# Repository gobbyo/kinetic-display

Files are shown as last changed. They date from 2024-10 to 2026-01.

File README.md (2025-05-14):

## Introduction

The Kinetic Display is an innovative and engaging way to showcase the current time, date, indoor temperature and humidity, and outdoor temperature and humidity. Watch the feature summary video below to see it in action. This robotic seven-segment clock-like display consists of 4 digits and 2 colons, totaling 30 actuators that extend and retract segments. Each segment lights up when extended and turns off when retracted, creating a satisfying clacking sound with every movement, adding a unique auditory experience.

See the full documentation, assembly instructions, and user guides at [https://gobbyo.github.io/kinetic-display/](https://gobbyo.github.io/kinetic-display/).

**Feature Summary**

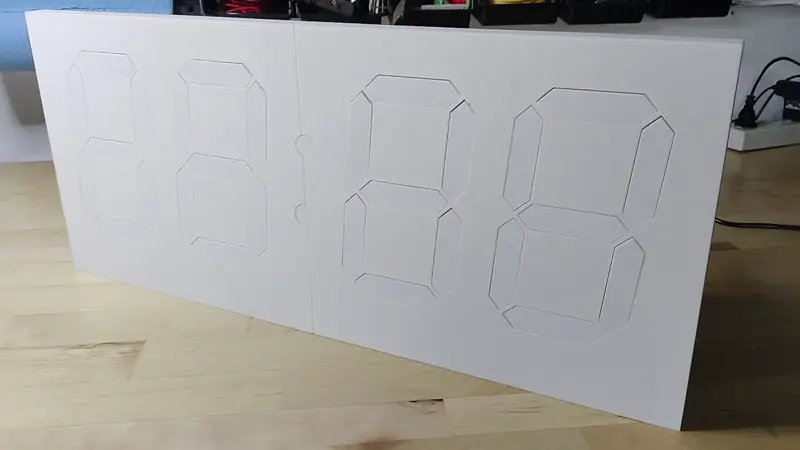
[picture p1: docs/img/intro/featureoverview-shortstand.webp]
summaryfeatures


The display features a built-in web service with adjustable settings that allow you to easily configure and personalize your display using any device with Wi-Fi and a web browser.

display-settings

Having adjustable settings for your kinetic display offers several advantages:

- **Personalization**: Tailor the display's schedule, time format, temperature units, and digit style to match your preferences and environment.
- **Convenience**: Make changes from your phone or computer without needing to reprogram or physically access the device.
- **Adaptability**: Quickly update Wi-Fi credentials, time zones, or schedules if you move the display or your needs change.
- **Reliability**: Built-in test and recovery options help ensure the display operates correctly after power loss or network changes.
- **Energy Efficiency**: Schedule sleep and wake times to save power and extend the life of your display.

Optional startup animation setting whenever the power is turned on or the display wakes up from low power mode.

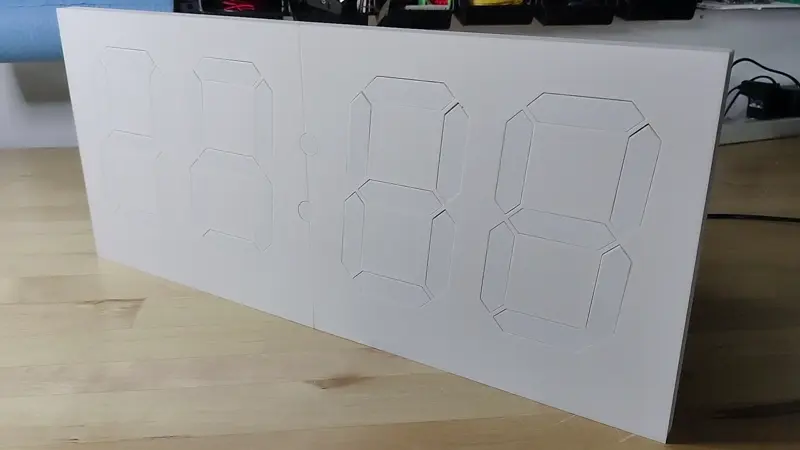
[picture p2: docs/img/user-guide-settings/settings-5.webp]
settings-5


Optional alien digit type setting. See the [table on human and alien digit type](./docs/userguide/digittype.md).

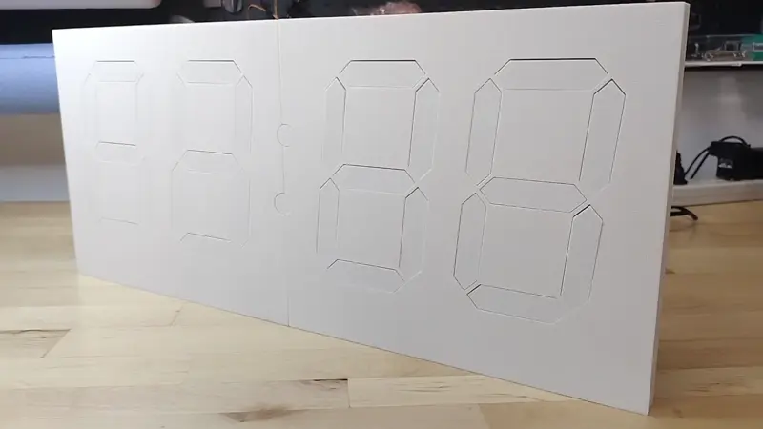
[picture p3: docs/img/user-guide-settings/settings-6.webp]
settings-6


Designed for durability, the display is built to last for years when assembled correctly by following the detailed documentation. Below is an overview of the iterative design process that led to the creation of a robust, reliable, and cost-effective display, fully 3D-printable on a 256mm x 256mm x 256mm build plate.

**Actuator Prototype**

The actuators are the heart of the display, and getting their design right was critical. Early prototypes revealed issues such as gear tooth breakage due to improper sizing, material selection, and abrupt stops during operation. Adjustments to gear dimensions and the use of heavy-duty 103 motors significantly improved performance, enabling smooth operation with lower voltage requirements.
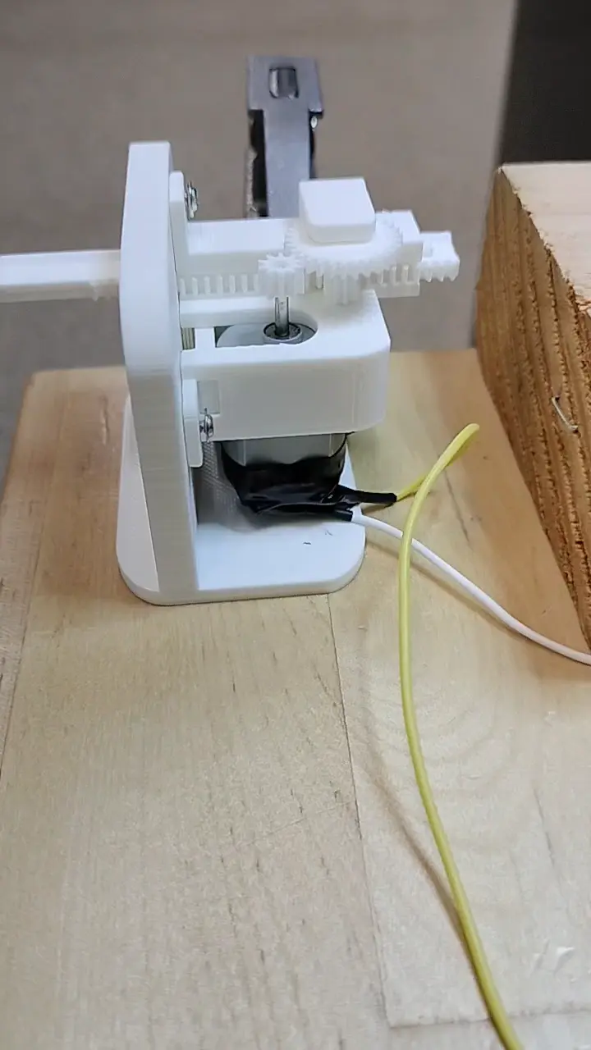
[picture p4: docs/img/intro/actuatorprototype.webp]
actuator


**Segment Prototype**

Multiple iterations of the segment design ensured the robustness of the segment head and its attachment to the rack gear. Experiments also determined the best cushioning material to absorb the impact of constant actuator movement.
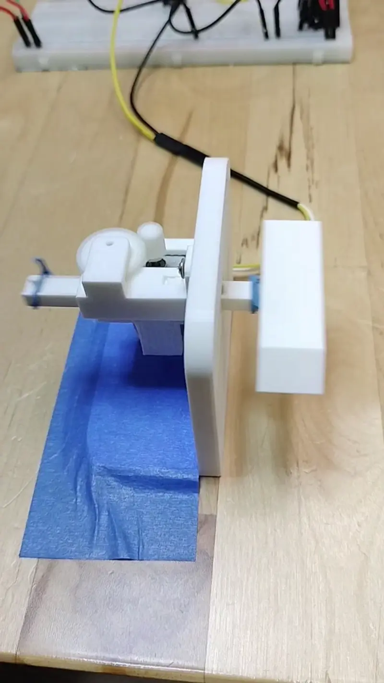
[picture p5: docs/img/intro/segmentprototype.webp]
segment


**Digit Prototype**

The first digit prototype provided valuable insights into PCB design, software requirements, and the optimal dimensions for positioning the seven actuators within a single digit.
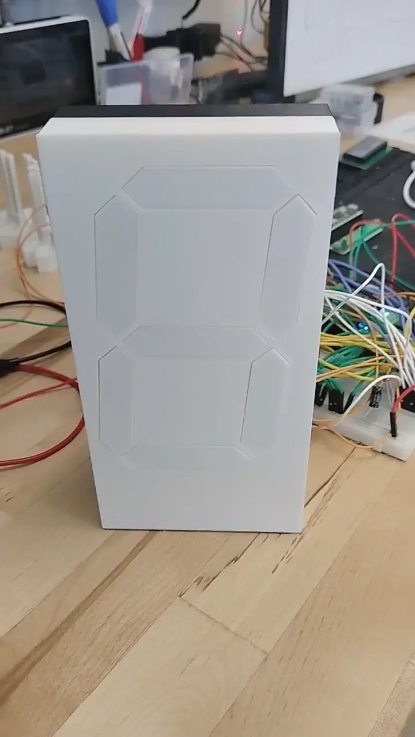
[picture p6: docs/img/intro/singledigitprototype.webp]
digit


**First Prototype**

The prototype below has been running continuously since April 2024, demonstrating the reliability and durability of the design.
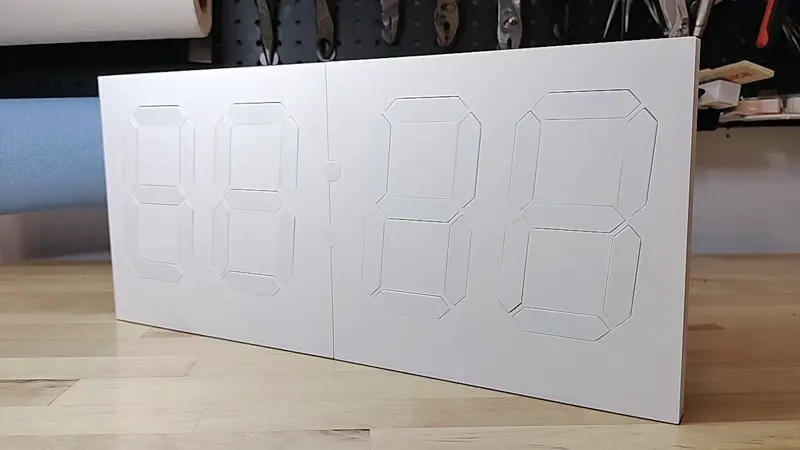
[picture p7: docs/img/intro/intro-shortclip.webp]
display


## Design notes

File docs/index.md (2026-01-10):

# Contents

The links listed below should be followed in the order they appear on the page from top to bottom. Use the `← Previous` and `Next →` buttons on the top menu bar to navigate.

## Start Here

- [Introduction](intro.md)
- [Verify REST API Dependencies](verifyapis.md)
- [Software and Micro Controller Preparation](prerequisitesoftware.md)

## Order Parts

- [Bill of Materials](./createandorder/bom.md)
- [Fabricate the Printed Circuit Boards (PCBs)](./createandorder/pcb.md)
- [Display Parts FDM Fabrication](./createandorder/3dprints.md)

## Assemble and Test Components

- [Actuator Assembly](./assembly/actuatorassembly.md)
- [Digit PCB Assembly](./assembly/digitpcbassembly.md)
- [Deploy Digit Project](./assembly/deploydigitproject.md)
- [Digit PCB Test](./assembly/digitpcbtest.md)
- [Conductor PCB Assembly](./assembly/controllerpcbassembly.md)
- [Deploy Conductor Project](./assembly/deploycontrollerproject.md)
- [Conductor PCB Test](./assembly/controllerpcbtest.md)
- [Power Management PCB Assembly](./assembly/powermanagementpcb.md)
- [Power Management PCB Test](./assembly/powermanagementpcbtest.md)
- [Buck Module Wiring](./assembly/buckmodulesandwiring.md)
- [UART and Relay Wiring](./assembly/uartandrelaywiring.md)
- [Display Face and PCBs Assembly with Integration Testing](./assembly/displayfacepcbs.md)
- [Backplate and Stand Assembly](./assembly/backplateassembly.md)
- [Segment Assembly and Installation](./assembly/segmentassembly.md)
- [Finishing Touch](./assembly/finishingtouch.md)

## User Guide

- [Orientation](./userguide/orientation.md)
- [On/Off Switch](./userguide/spdtswitch.md)
- [Web Service and Settings](./userguide/websettings.md)
- [Schedule Creation and Management](./userguide/schedule.md)
- [Table of Human and Alien Digit Type](./userguide/digittype.md)

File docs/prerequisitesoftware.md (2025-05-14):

# Software and Microcontroller Preparation

If you have any problems with this documentation or the code, please create a [new issue](https://github.com/gobbyo/kinetic-display/issues/new/choose) on the Kinetic-Display GitHub site.

## Prerequisites

Before you begin, please:

- Read and bookmark the [MicroPython installation guide for Raspberry Pi Pico](https://www.raspberrypi.com/documentation/microcontrollers/micropython.html#what-is-micropython).

### 1. Install Required Software

1. [Download and install Visual Studio Code](https://code.visualstudio.com/download).
2. Open VS Code and click the **Extensions** icon on the [Activity Bar](https://code.visualstudio.com/docs/getstarted/userinterface#_basic-layout).
3. Search for and install these extensions from the [Marketplace](https://code.visualstudio.com/docs/editor/extension-marketplace):
    - **Python** by Microsoft
    - **MicroPico** by paulober

### 2. Prepare Your Raspberry Pi Pico

1. Download the [flash_nuke UF2 file](https://github.com/Pwea/Flash-Nuke).
2. Clear your Raspberry Pi Pico before flashing a new build:
    - Unplug your Pico from USB if it is connected.
    - Press and hold the **BOOTSEL** button on your Pico while plugging it into your computer's USB port.
    - Wait for the **RPI-RP2** storage device to appear on your computer.
    - Drag and drop the **flash_nuke.uf2** file onto the RPI-RP2 drive.
3. Download the MicroPython UF2 file for your device:
    - [Raspberry Pi Pico](https://micropython.org/download/RPI_PICO/)
    - [Raspberry Pi Pico W](https://micropython.org/download/RPI_PICO_W/)

---

## Verify MicroPython on Your Raspberry Pi Pico

1. Open Visual Studio Code.
2. On the top menu, select the **ellipsis ...** (if present), then **Terminal → New Terminal**.
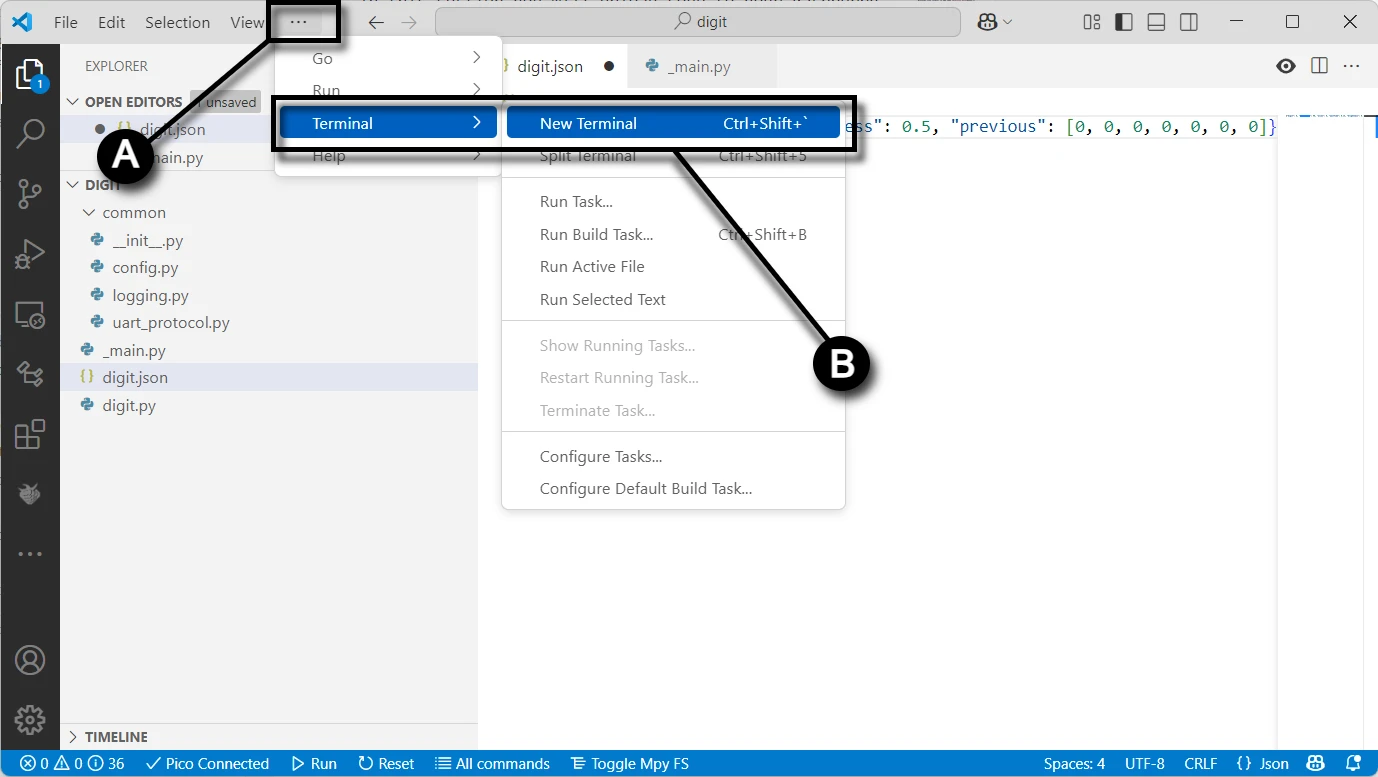
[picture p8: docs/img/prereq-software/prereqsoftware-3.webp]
micropico-0
   
3. In the terminal pane, select the terminal menu, then the MicroPico vREPL sub-menu.
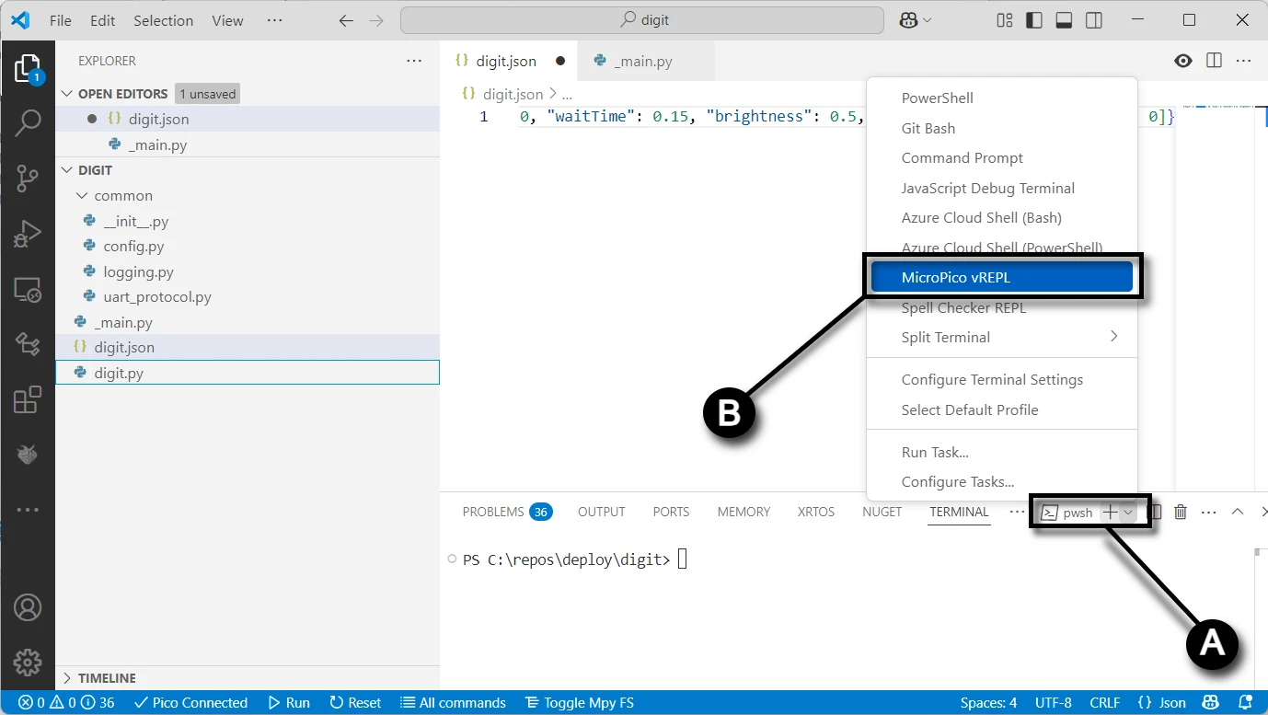
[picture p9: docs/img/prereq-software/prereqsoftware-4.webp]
micropico-1
   
4. Plug your Raspberry Pi Pico into the USB port. The [Status bar](https://learn.microsoft.com/en-us/visualstudio/extensibility/vsix/recipes/notifications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) will show your Pico as connected.
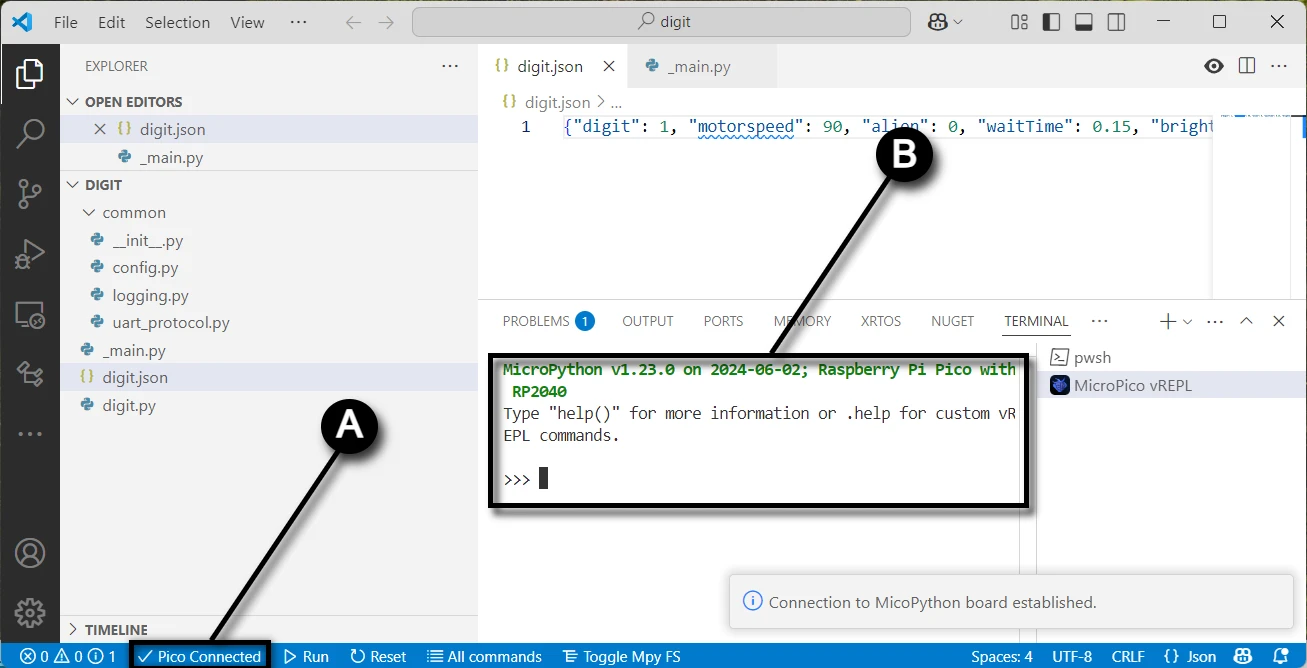
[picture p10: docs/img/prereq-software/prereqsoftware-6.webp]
micropico-3
   
5. Verify your Pico's onboard LED turns on and off by typing the following code in the terminal pane (copy/paste each line separately):

```python
from machine import Pin
p = Pin(25, Pin.OUT)
p.on()
p.off()
```

---

## Fork and Clone the Repository

1. [Install Git](https://git-scm.com/downloads) for Windows.
2. Go to the [Kinetic-Display GitHub repository](https://github.com/gobbyo/kinetic-display).
3. [Create a fork](https://docs.github.com/en/pull-requests/collaborating-with-pull-requests/working-with-forks/fork-a-repo) of the repository.
4. If you have never used PowerShell before:
    - Open a new **PowerShell** terminal as administrator (search for "Windows PowerShell" in the Start menu).
    - Run: `Set-ExecutionPolicy -ExecutionPolicy Unrestricted -Scope CurrentUser`
    - Verify with: `Get-ExecutionPolicy -List` (ensure `CurrentUser` is set to `Unrestricted`).
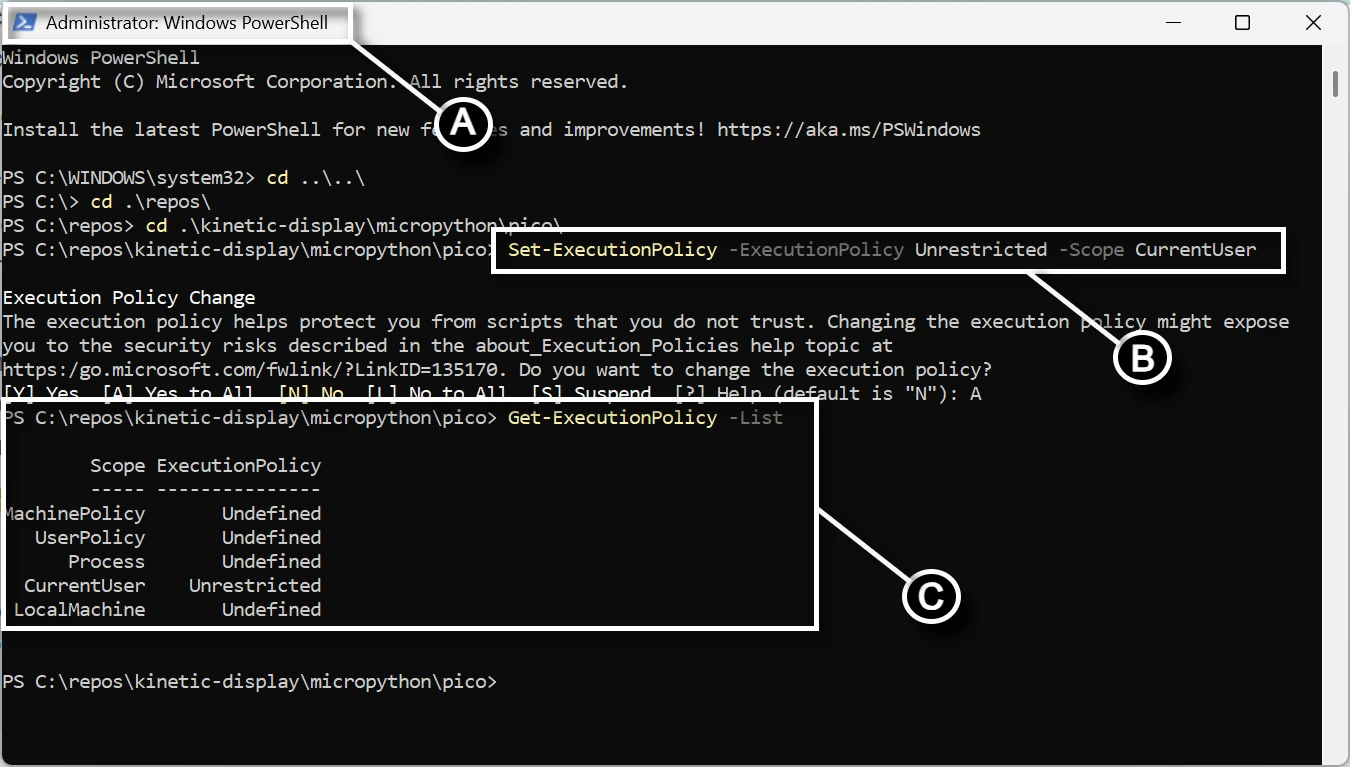
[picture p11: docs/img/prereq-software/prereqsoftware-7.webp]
prereqsoftware-7
    - 
5. Otherwise, open a new **PowerShell** terminal (no admin needed).
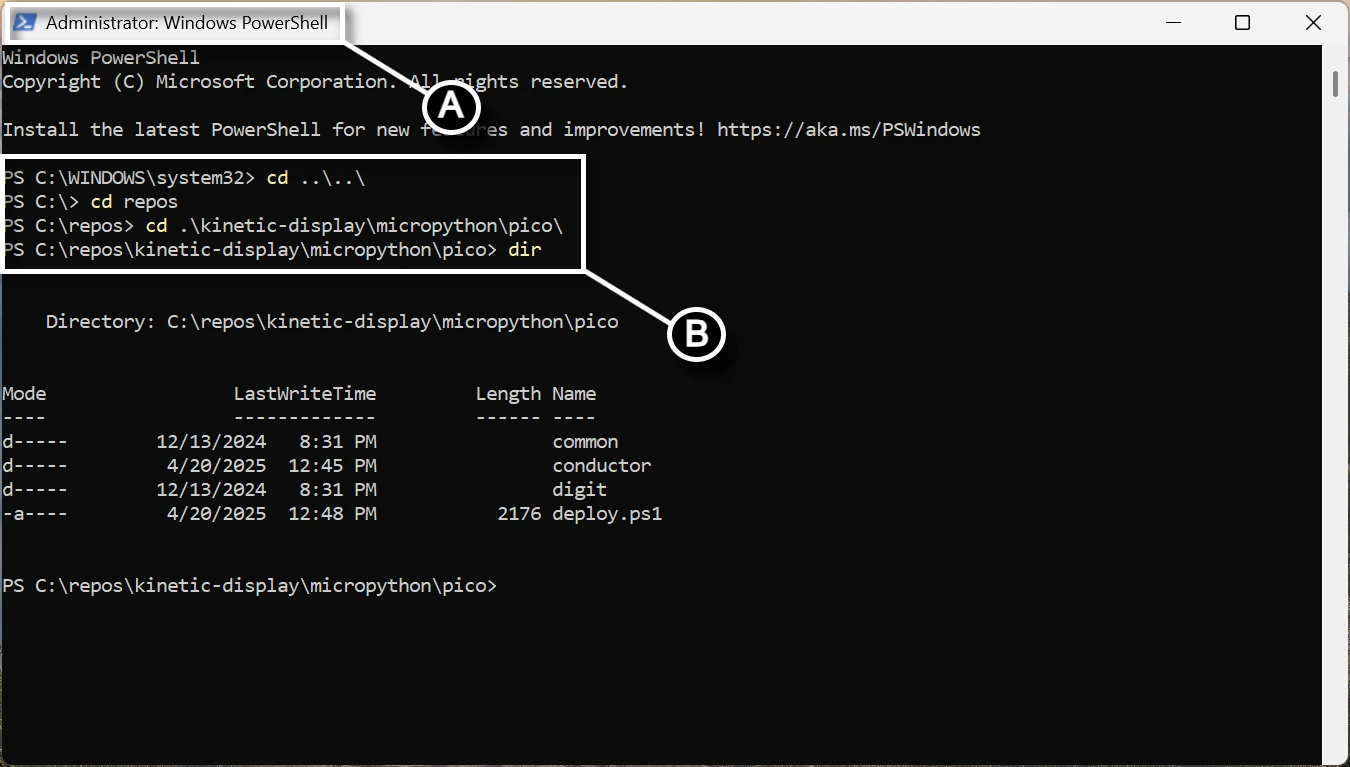
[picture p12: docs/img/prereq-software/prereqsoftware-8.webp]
prereqsoftware-8
   
6. Change directory to your cloned repo's `kinetic-display\micropython\pico` folder.
7. Run the command: `./deploy.ps1 <directorypath>` (replace `<directorypath>` with your desired folder, e.g., `./deploy.ps1 "c:\deploy"`).
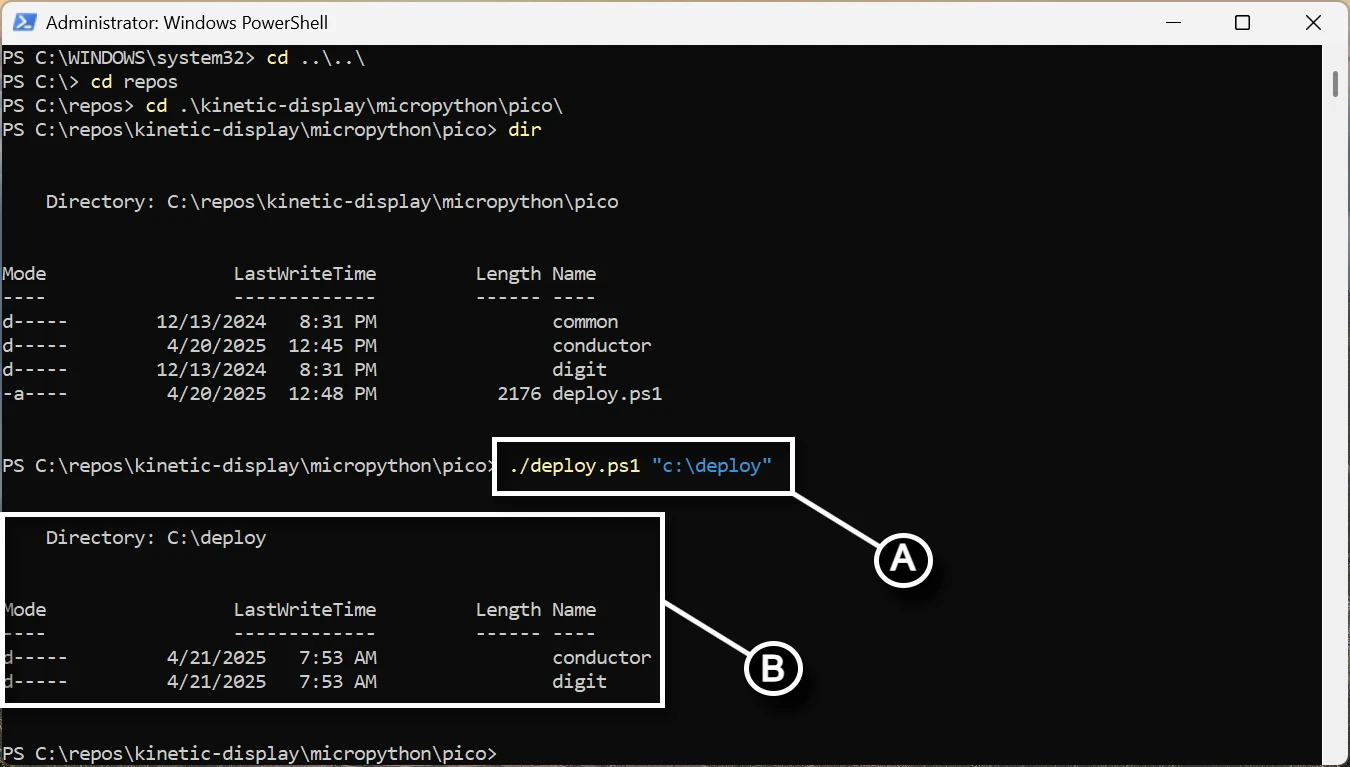
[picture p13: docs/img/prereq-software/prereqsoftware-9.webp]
prereqsoftware-9
   

!!! warning
    The folder you provide for `<directorypath>` will be deleted along with all its contents when you run the `deploy.ps1` script. Be sure to save or rename the folder if you want to preserve any changes you made.

If successful, you should see output like this, and the `conductor` and `digit` folders should exist in your deployment directory:

```dos
Directory: C:\deploy

Mode                 LastWriteTime         Length Name
----                 -------------         ------ ----
d-----         1/31/2025   8:30 PM                conductor
d-----         1/31/2025   8:30 PM                digit
```

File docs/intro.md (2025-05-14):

# Kinetic Display

gobbyo | jbeman@hotmail.com

## Introduction

The Kinetic Display is an innovative and engaging way to showcase the current time, date, indoor temperature and humidity, and outdoor temperature and humidity. Watch the feature summary video below to see it in action. This robotic seven-segment clock-like display consists of 4 digits and 2 colons, totaling 30 actuators that extend and retract segments. Each segment lights up when extended and turns off when retracted, creating a satisfying clacking sound with every movement, adding a unique auditory experience.

**Feature Summary**

summaryfeatures

The display features a built-in web service with adjustable settings that allow you to easily configure and personalize your display using any device with Wi-Fi and a web browser.

display-settings

Having adjustable settings for your kinetic display offers several advantages:

- **Personalization**: Tailor the display's schedule, time format, temperature units, and digit style to match your preferences and environment.
- **Convenience**: Make changes from your phone or computer without needing to reprogram or physically access the device.
- **Adaptability**: Quickly update Wi-Fi credentials, time zones, or schedules if you move the display or your needs change.
- **Reliability**: Built-in test and recovery options help ensure the display operates correctly after power loss or network changes.
- **Energy Efficiency**: Schedule sleep and wake times to save power and extend the life of your display.

Optional startup animation setting whenever the power is turned on or the display wakes up from low power mode.
settings-5

Optional alien digit type setting.
settings-6

Designed for durability, the display is built to last for years when assembled correctly by following the detailed documentation. Below is an overview of the iterative design process that led to the creation of a robust, reliable, and cost-effective display, fully 3D-printable on a 256mm x 256mm x 256mm build plate.

**Actuator Prototype**

The actuators are the heart of the display, and getting their design right was critical. Early prototypes revealed issues such as gear tooth breakage due to improper sizing, material selection, and abrupt stops during operation. Adjustments to gear dimensions and the use of heavy-duty 103 motors significantly improved performance, enabling smooth operation with lower voltage requirements.
actuator

**Segment Prototype**

Multiple iterations of the segment design ensured the robustness of the segment head and its attachment to the rack gear. Experiments also determined the best cushioning material to absorb the impact of constant actuator movement.
segment

**Digit Prototype**

The first digit prototype provided valuable insights into PCB design, software requirements, and the optimal dimensions for positioning the seven actuators within a single digit.
digit

**First Prototype**

The prototype below has been running continuously since April 2024, demonstrating the reliability and durability of the design.
display

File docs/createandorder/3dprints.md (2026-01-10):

# Display Parts FDM Fabrication

## Filament Quantity

Below is a table of quantities of filament by weight. Since a roll of filament is generally 1000g (sometimes a bit less), you'll need two rolls of White Matte PLA.

| Type | Weight (g) |
| :--- | ---: |
| Black Nylon | 77.1g |
| Black Matte PLA| 272.42g |
| White Matte PLA| 1535.44g |
| Black TPU | 115.15g |

</p>

## **1. Black Nylon, Smooth Build Plate**

For Orca and Bambu Studio slicers, see `fdm\3mf\nylon-smooth-black.3mf`.

| File | Description | Density | Quantity | Per Unit (g) | Total (g) |
| :--- | :--- | ---: | ---: | ---: | ---: |
| `digit-gear30.stl` | Pinion gear for digits and colons | 100% | 30 | 1.1  | 33.0 |
| `rack-gear.stl` | The arm of the actuator that extends and retracts the segment | 25% | 30 | 1.47 | 44.1 |

</p>

## **2. Black Matte PLA, Smooth Build Plate**

For Orca and Bambu Studio slicers, see `fdm\3mf\pla-smooth-black.3mf`.

| File | Description | Density | Quantity | Per Unit (g) | Total (g) |
| :--- | :--- | ---: | ---: | ---: | ---: |
| `digit-back-plate.stl`| Back plates for digits 0 and 3 for mounting the actuators | 50% | 2 | 47.43 | 142.29 |
| `digit-gear10.stl` | Motor shaft gear mounted onto the heavy-duty 103 motors | 100% | 30 | 0.5 | 15 |
| `digit1-back-plate.stl`| Conductor and digit 1 back plate for mounting the actuators | 50% | 1 | 67.7 | 67.7 |
| `digit2-back-plate.stl`| Back plate for digit 2 for mounting the actuators and powerbank/display stand | 50% | 1 | 47.43 | 47.43 |

</p>

## **3. White Matte PLA, Smooth Build Plate**

You have two options: `powerbank.stl` or `powerbank-small.stl`. Print the `powerbank.stl` and `powerbank-cover.stl` if you have household animals that might have access to the back of the display. Print `powerbank-small.stl` to keep a lower profile of the back of the display. Mounting `powerbank.stl` and `powerbank-small.stl` is the same for both sizes.

For Orca and Bambu Studio slicers, see `fdm\3mf\pla-smooth-white.3mf`.

| File | Description | Density | Quantity | Per Unit (g) | Total (g) |
| :--- | :--- | ---: | ---: | ---: | ---: |
| `digit-motor-mount.stl`| Motor mount for digits and colons | 100% | 30 | 12.77 | 383.1 |
| `powerbank-cover.stl` | Cover for large stand (optional) | 100% | 1 | 65.53 | 65.53 |
| `powerbank.stl` | Large stand (optional), buck converter mounts, and powerbank PCB mount | 100% | 1 | 146.75 | 146.75 |
| `powerbank-small.stl` | Small stand (preferred), buck converter mounts, and powerbank PCB mount | 100% | 1 | 116 | 116 |
| `rackgear-bumper.stl` | Stops the segment or colon at the precise distance when extended | 100% | 30 | 0.61 | 18.3 |
| `seg-pin.stl` | Pin to hold the rack gear onto the segment and colons | 100% | 30 | 0.4 | 12 |

## **4. White Matte PLA, Textured Build Plate**

For Orca and Bambu Studio slicers, see `fdm\3mf\pla-textured-white.3mf`.

| File | Description | Density | Quantity | Per Unit (g) | Total (g) |
| :--- | :--- | ---: | ---: | ---: | ---: |
| `colon-seg.stl` | Colon, upper and lower | 100% | 2 | 1.88 | 3.76 |
| `digit0-1-face.stl` | Kinetic display face, right side (when facing the front, textured surface side) | 70% | 1 | 395 | 395 |
| `digit2-3-face.stl` | Kinetic display face, left side (when facing the front, textured surface side) | 70% | 1 | 399 | 399 |
| `seg-a.stl` | Digit 7-segment A | 100% | 4 | 4 | 16 |
| `seg-b.stl` | Digit 7-segment B | 100% | 4 | 4 | 16 |
| `seg-c.stl` | Digit 7-segment C | 100% | 4 | 4 | 16 |
| `seg-d.stl` | Digit 7-segment D | 100% | 4 | 4 | 16 |
| `seg-e.stl` | Digit 7-segment E | 100% | 4 | 4 | 16 |
| `seg-f.stl` | Digit 7-segment F | 100% | 4 | 4 | 16 |
| `seg-g.stl` | Digit 7-segment G | 100% | 4 | 4 | 16 |

## **5. Black TPU, Smooth Build Plate**

For Orca and Bambu Studio slicers, see `fdm\3mf\tpu-smooth-black.3mf`.

| File | Description | Density | Quantity | Per Unit (g) | Total (g) |
| :--- | :--- | ---: | ---: | ---: | ---: |
| `digit-gasket.stl` | Gaskets for digits 0 and 3 to cushion the PCB during segment retractions | 15% | 2 | 17.86 | 53.58 |
| `digit1-gasket.stl` | Gasket for the conductor and digit 1 to cushion the PCB during segment retractions | 15% | 1 | 31.71 | 31.71 |
| `digit2-gasket.stl` | Gasket for digit 2 to cushion the PCB during segment retractions | 15% | 1 | 17.86 | 17.86 |
| `rackgear-bumper-gasket.stl` | Provides some cushion for the rack gear when extended | 100% | 30 | 0.4 | 12 |

## Guidelines

Below are a few guidelines to keep in mind when printing and assembling the display:

- **Read the assembly guides**: Read all the assembly guides in this documentation before printing to ensure you have a clear understanding of the fabrication type, quality, positioning, and assembly.
- **Use the provided 3MF and STL files**: The 3MF project files are included under the `./fdm/3mf` directory for Bambu Studio or Orca Slicer users. All necessary settings are included at an object level, not on a global level. STL files are included under the `./fdm/stl` directory.
- **Consistent filament usage**: The display face uses over 2/3rds of a 1 KG roll of filament. Use the same roll of filament when printing both halves of the display face, segments, and colons. Ensure you have two 1 KG rolls of white filament from the same batch to avoid inconsistencies in print color.
- **Dry your filament**: Thoroughly dry your filament before use, especially nylon and flexible filament types. Wet filament can cause stringy prints and result in inexact gear teeth or hole sizes.
- **Adhesion to the print bed**: Apply an adhesive to the printer plate bed to prevent warping of edges and corners. For example, all-weather Aqua Net super hold hairspray provides an even coating of adhesive across the bed plate and results in clean corners and edges.
- **Organize printed parts**: Use painter's tape to keep the pieces organized. See the picture below for an example. Note that segments A-G (left to right) are preserved the moment the bed plate is removed from the 3D printer.  
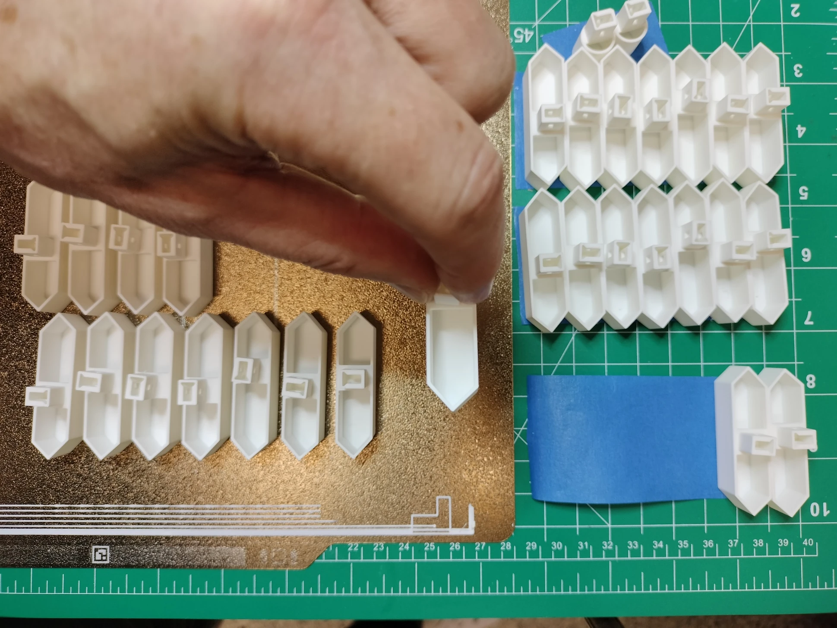
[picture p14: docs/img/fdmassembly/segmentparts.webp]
fdmassembly
  
- **Ironing is optional**: Do not worry if your 3D printer and slicer cannot iron the top surfaces. Ironing is for fit and finish and will not affect the functionality of the display.

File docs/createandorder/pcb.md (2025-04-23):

# Fabricate the Printed Circuit Boards (PCBs)

This guide will help you order the fabrication of your PCBs. The PCB files are located in your fork at `kinetic-display\pcb`. Follow the instructions below to place a separate order for each of the three Gerber files:

- `Gerber_KineticDisplay-Controller`
- `Gerber_KineticDisplay-PowerSystem`
- `Gerber_KineticDisplay-SingleDigit`

You will need to order more PCBs than required for this project because most PCB fabrication facilities have a minimum order quantity of five. Be sure to also order the remaining components and materials from the [Bill of Materials (BOM)](bom.md).

## Steps to Order PCBs

1. Open your browser and navigate to [https://jlcpcb.com/](https://jlcpcb.com/). Create an account if you do not already have one, then click the **Order now** button.  
   Click the 'order now' button
2. Upload the Gerber file by clicking the **Add Gerber file** button. Repeat this step through step 4 for each of the three Gerber files found under the `kinetic-display\pcb` directory.  
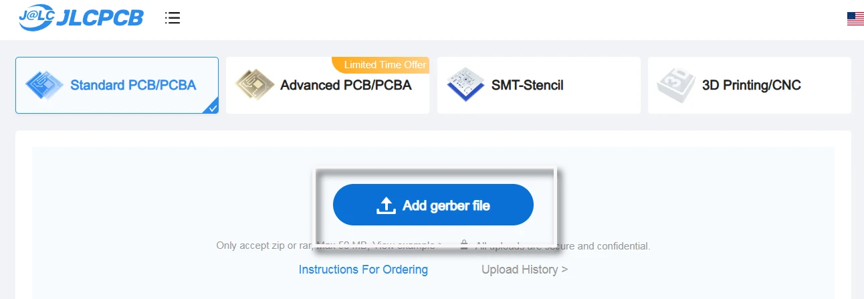
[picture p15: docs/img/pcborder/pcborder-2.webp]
Click the 'Add Gerber file' button
   
3. Use all the default settings except change the PCB color to **white** to enhance the luminosity of the LEDs.  
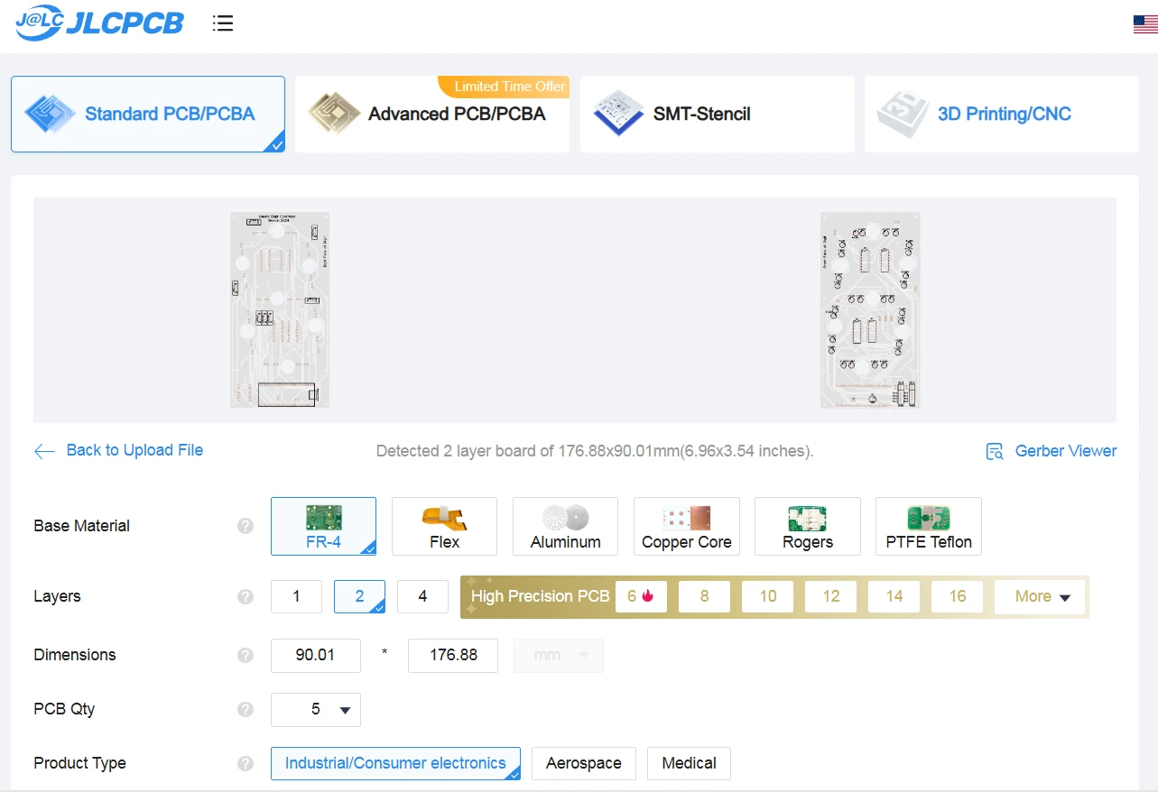
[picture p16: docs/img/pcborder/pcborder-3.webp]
   
4. Click the **SAVE TO CART** button and complete the order by following the shipping and payment steps in the wizard.  
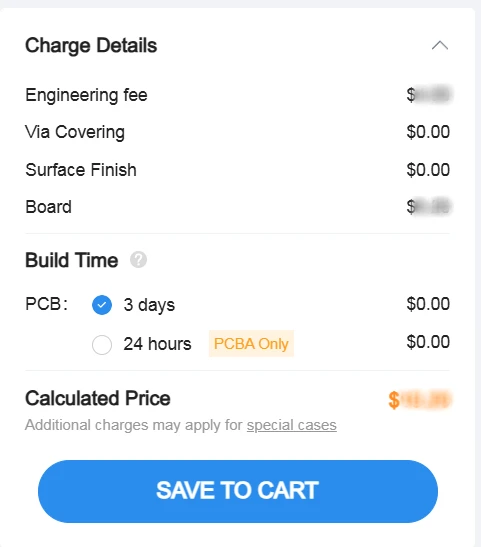
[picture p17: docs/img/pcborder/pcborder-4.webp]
   

## Notes

- **PCB Color**: White PCBs are recommended to maximize LED brightness and improve the overall aesthetic of the display.
- **Minimum Order Quantity**: Most PCB manufacturers require a minimum order of five PCBs per design. This means you will receive extra PCBs, which can be used as spares or for future projects.
- **Shipping and Lead Time**: Be sure to check the estimated shipping time and lead time for fabrication when placing your order.

Congratulations on ordering your PCBs!

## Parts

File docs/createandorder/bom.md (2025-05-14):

# Bill of Materials

| Item | Quantity |
|---|---|
| Single digit PCB for digits 0, 2, & 3 | 3 |
| Conductor PCB for digit 1 and the colons | 1 |
| Powerbank PCB | 1 |
| 2 Inch Jumbo Paper Clips (Smooth Big Paperclips) | 20 |
| M1.7 x 6mm Stainless Steel Phillips Round Head Self Tapping Screws | 200 |
| M1.7 x 8mm Stainless Steel Phillips Round Head Self Tapping Screws | 200 |
| M2 X 15mm Stainless Steel Phillips Round Head Self Tapping Screws | 50 |
| Micro 130 DC Motor Strong Magnetic Brushed Electric DC 3V -12V 25000 RPM Cars Toys Electric Motor, High Speed Torque | 30 |
| Black 28 AWG Gauge Flexible Silicone Rubber Electric Wire | 10M |
| White 28 AWG Gauge Flexible Silicone Rubber Electric Wire | 10M |
| Male Breakout Pin Connector 2.54mm | 100 |
| 2.54mm 0.1" Pitch PCB Mount Screw Terminal Block Connector, 2P 3P 4P Terminals for 26-18AWG Cable | 50 |
| Dupont Jumper Wire Cable Female Pin Connector 2.54mm | 100 |
| 2.54mm 1x2p Dupont Connector Housing Female for Dupont Cable and Jumper Wire | 100 |
| Digital Temperature and Humidity Sensor DHT22 Module, 3 pin | 1 |
| 5mm 0.5 Ω ohm Photoresistor Resistor 5516 GL5516 | 1 |
| 5mm Flat Top LED Diode Lights[^1] (Clear Transparent Lens) Bright Lighting Bulb Lamps Electronics Components Indicator Light Emitting Diodes | 112 |
| 3mm Flat Top LED Diode Lights[^1] (Clear Transparent Lens) Bright Lighting Bulb Lamps Electronics Components Indicator Light Emitting Diodes | 2 |
| Vertical Slide Switches Micro High Knob 3 Pin 2 Position 1P2T SPDT Panel Mount AC 125V 2A | 1 |
| LM2596 DC-DC Step Down Variable Volt Regulator Input 3.2V-40V Output 1.25V-35V Adjustable Buck Converter Electronic Voltage Stabilizer Power Supply Module | 5 |
| 2.1mm Barrel Jack 5.5x2.1mm Female DC Power Jack 2.1 X 5.5mm DC Jack Connector 6V 9V 12V DC Jack Panel Mount | 1 |
| 12V 5A Power Supply, AC DC Converter 100-220V to 12 Volt 5 Amp Transformer 5.5x2.1mm Plug | 1 |
| S8050D S8050 NPN Transistor TO-92 20V 700MA 1W | 1 |
| 1N4001 Diode, standard, 1A, 50V, DO-41 | 1 |
| (optional) 20pin x 10pcs Female Headers Pins Straight Single Row Gold Plated Pitch 2.54mm 0.1 inch for PCB Connector Machine Breadboard Electronic Circuit Board | 10 |
| SONGLE SRS-05VDC-SL 05VDC-SL 4100 Blue 5V 6PIN Power Relay | 1 |
| L293D 16-pin IC Stepper Motor Drivers Controller | 17 |
| 0.1uF Ceramic Disc Capacitor - 50 Volts | 5 |
| 1uF Electrolytic Capacitor 1UF-50V-5X11 | 5 |
| S8550 TO-92 PNP Transistor | 1 |
| 2N2222 TO-92 NPN Transistor | 1 |
| 10K ohm 0805 Resistor 1/4w Metal Film Fixed Resistor | 2 |
| 1K ohm 0805 Resistor 1/4w Metal Film Fixed Resistor | 1 |
| Raspberry pi 2040 Pico | 4 |
| Raspberry pi 2040 Pico-W | 1 |
| Superglue (small tube) | 1 |
| White Matte PLA Filament, 1 KG | 2 |
| Black Matte PLA Filament, 1 KG | 1 |
| Black Nylon Filament, 1 KG | 1 |
| Black TPU Filament, 1 KG | 1 |

## Tools

- 3D printer
- Wire Stripper for 28 AWG stranded wire
- Small Philips head screwdriver
- Dupont connector tool
- Soldering station with solder/flux
- Needle nose pliers
- Tweezers
- Clamping tweezers
- Zinc strip or thin metal strip (for melting PLA)
- Wire snipper
- Multimeter
- Breadboard and jumpers for testing electronics
- Label maker (optional)
- Computer with USB connector

[^1]: You can choose any color of LED that you would like for your display. White LEDs are the easiest to work with as they may have minor color variation within the same batch. Colored LEDs like blue or warm white may greatly vary in color within the same batch. Therefore, you may need to order more than the quantity listed in the BOM to get enough LEDs of the same color. Be sure to test your LEDs by using your phone's digital camera to see if there are any variations in color when the LEDs are lit. Below is a photo showing the color variation of blue 5mm LEDs within the same batch using a breadboard's power rail with 2.63v. In this case, I used the purple-hued LEDs because there were 112 of the same color.  
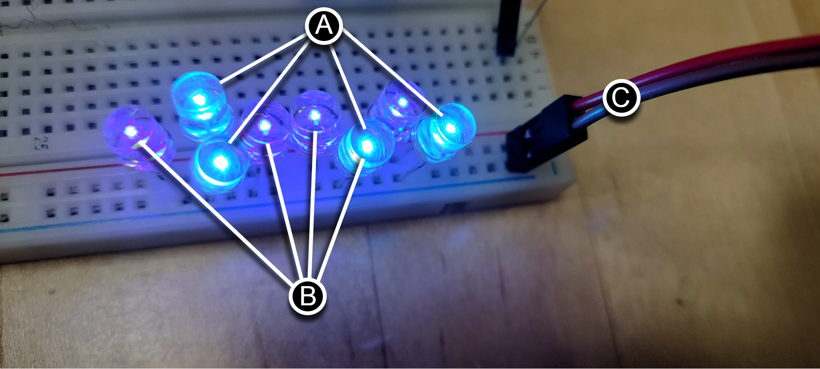
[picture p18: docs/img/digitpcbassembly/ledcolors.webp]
blueLEDs


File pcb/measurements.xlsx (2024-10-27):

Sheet: bom
Quantity | Item | Items Per Package | Quantity per Package | Unit cost | Sub Total | % of overall cost | Cost DIY
4 | RP2040-Pico Microcontroller | 1 | 2 | $7.00 | $14.00 | 9.1% | $14.00
1 | ESP32 S2 Mini WIFI Microcontroller | 1 | 1 | $5.00 | $5.00 | 3.3% | $5.00
18 | L293D Stepper Push-Pull Motor Driver Controllers IC 16-Pin DIP-16 4.5V-36V | 10 | 1.8 | $8.99 | $16.18 | 10.5% | $17.98
30 | Micro 130 DC Motor Strong Magnetic Brushed Electric DC 3V -12V, 17g weight | 10 | 3 | $11.99 | $35.97 | 23.4% | $35.97
120 | 5mm Flat Top LED Diode Lights (Clear Transparent Lens) | 100 | 1.2 | $6.99 | $8.39 | 5.5% | $13.98
2 | Self Adhesive Felt Sheet, Peel and Stick, 2mm thick, A4 Size (8.3" x 11.8") | 4 | 0.5 | $4.99 | $2.50 | 1.6% | $4.99
2 | Self Adhesive Felt Sheet, Peel and Stick Felt Liner, A4 Size (8.3" x 11.8") | 10 | 0.2 | $7.99 | $1.60 | 1.0% | $7.99
60 | Dupont Jumper Wire Cable Female Pin Connector 2.54mm | 200 | 0.3 | $6.99 | $2.10 | 1.4% | $6.99
30 | Dupont 2 Plug Connector Housing | 200 | 0.15 | $11.99 | $1.80 | 1.2% | $11.99
32 | M2x15mm Thread Nickel Plated Round Head Self Tapping Screws | 50 | 0.64 | $7.49 | $4.79 | 3.1% | $7.49
32 | M1.7x8mm Thread Nickel Plated Round Head Self Tapping Screws | 100 | 0.32 | $10.39 | $3.32 | 2.2% | $10.39
90 | M1.7x6mm Thread Nickel Plated Round Head Self Tapping Screws | 100 | 0.9 | $9.99 | $8.99 | 5.9% | $9.99
5 | 1u capacitor | 80 | 0.0625 | $6.99 | $0.44 | 0.3% | $6.99
5 | 0.1u capacitor | 25 | 0.2 | $5.50 | $1.10 | 0.7% | $5.50
1 | 5mm 5 ohm photoresistor GL5539 | 20 | 0.05 | $5.49 | $0.27 | 0.2% | $5.49
1 | DHT11 (3 pin) temperature and humidity sensor | 10 | 0.1 | $12.99 | $1.30 | 0.8% | $12.99
2 | 5V 0.3A Mini Size Black SPDT Slide Switch | 20 | 0.1 | $6.89 | $0.69 | 0.4% | $6.89
1 | USB 3.1 Type C Connector Board, Serial Basic Breakout Female Connector | 10 | 0.1 | $8.59 | $0.86 | 0.6% | $8.59
10 | Large Paper Clips, Jumbo 2 inch smooth | 300 | 0.03333333333 | $8.99 | $0.30 | 0.2% | $8.99
1 | DC 5.1v 5A Power Supply | 1 | 1 | $12.99 | $12.99 | 8.5% | $12.99
4 | PCB Digit | 5 | 0.8 | $30.89 | $24.71 | 16.1% | $30.89
1 | PCB Controller | 5 | 0.2 | $30.89 | $6.18 | 4.0% | $30.89
 | Total |  |  |  | $153.48
 | Tax |  |  | 8.80% | $166.98
 | DIY Total |  |  |  | $276.97
 | DIY w Tax |  |  |  | $301.34

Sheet: pcb holes
 | X (mm) | Y (mm)
dimensions | 94 | 154
midpoint | -47 | 77
hole-seg-a | -2.4 | 60.5
hole-seg-b | -33.9 | 31.6
hole-seg-c | -28.96 | -29.92
hole-seg-d | 7.3 | -61.92
hole-seg-e | 31.74 | -24.52
hole-seg-f | 27 | 29.4
hole-seg-g | -2.4 | 0.1
hole-seg-a-tab-a | -14.4 | 61
hole-seg-a-tab-b | 18.34 | 63
hole-seg-a-tab-c | 10.59 | 39.21
hole-seg-b-tab-a | -34.65 | 19.62
hole-seg-b-tab-b | -36.69 | 52.36
hole-seg-b-tab-c | -12.83 | 44.62
hole-seg-c-tab-a | -40.95 | -29.19
hole-seg-c-tab-b | -8.2 | -27.15
hole-seg-c-tab-c | -15.95 | -51.02
hole-seg-d-tab-a | 6.57 | -73.92
hole-seg-d-tab-b | 4.53 | -41.17
hole-seg-d-tab-c | 28.39 | -48.92
hole-seg-e-tab-a | 43.73 | -25.37
hole-seg-e-tab-b | 10.99 | -27.4
hole-seg-e-tab-c | 18.74 | -3.54
hole-seg-f-tab-a | 27.8 | 41.38
hole-seg-f-tab-b | 29.84 | 8.63
hole-seg-f-tab-c | 5.98 | 16.38
hole-seg-g-tab-a | 9.62 | -0.95
hole-seg-g-tab-b | -23.12 | -2.99
hole-seg-g-tab-c | -15.37 | 20.87
hole-mount-a | -41.5 | 74
hole-mount-b | 41.5 | 74
hole-mount-c | -41.5 | 0
hole-mount-d | 41.5 | 0
hole-mount-e | -41.5 | -65
hole-mount-f | 41.5 | -65
hole-mount-g | -41.5 | -95.5
hole-mount-h | 41.5 | -95.5
hole-upper-inside-a | -25 | 50
hole-upper-inside-b | 15 | 50
hole-upper-inside-c | -21 | 10
hole-upper-inside-d | 19 | 10
hole-lower-inside-a | 19 | -10
hole-lower-inside-b | -21 | -10
hole-lower-inside-c | 15 | -50
hole-lower-inside-d | -25 | -50

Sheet: pcb sizes
 | mm | pixel
width | 90 | 340
height | 176 | 666
ppi

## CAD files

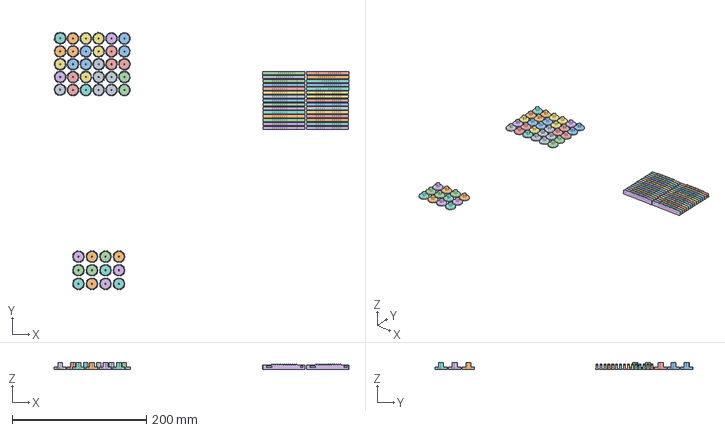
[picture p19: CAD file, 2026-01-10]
fdm/3mf/nylon-smooth-black.3mf
439.9 x 384.4 x 9.70 mm
digit-gear30.stl x 42
rack-gear.stl x 30

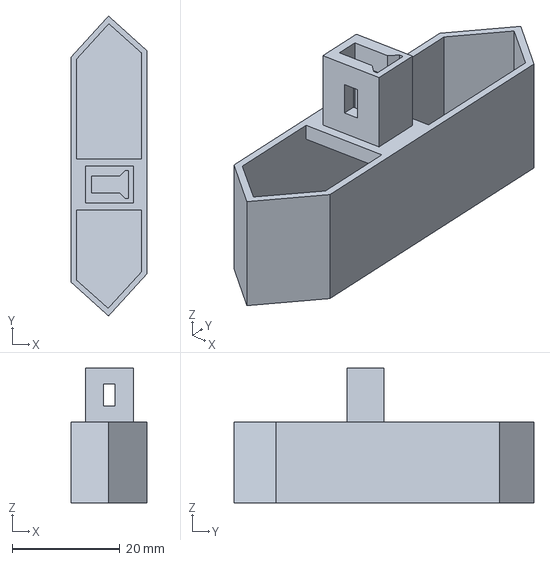
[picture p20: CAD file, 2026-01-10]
fdm/stl/seg-a.3mf
14.0 x 55.6 x 25.0 mm

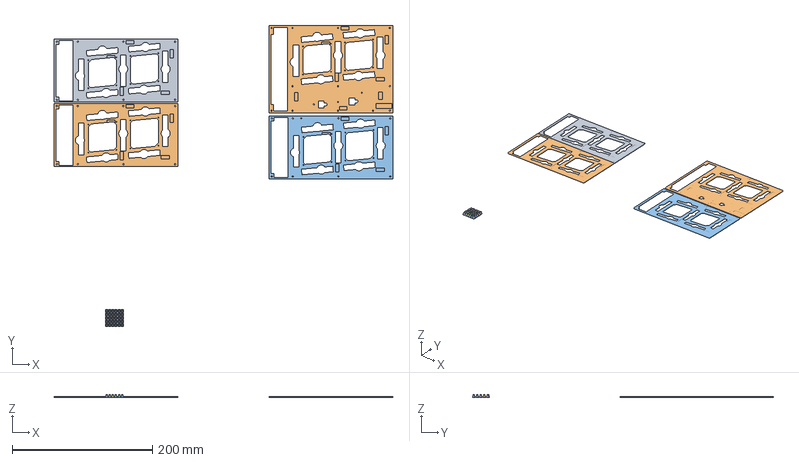
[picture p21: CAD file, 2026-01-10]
fdm/3mf/tpu-smooth-black.3mf
484.2 x 429.8 x 4.90 mm
digit-gasket.stl x 2
digit2-gasket.stl
rackgear-bumper-gasket.stl x 30
digit1-gasket.stl

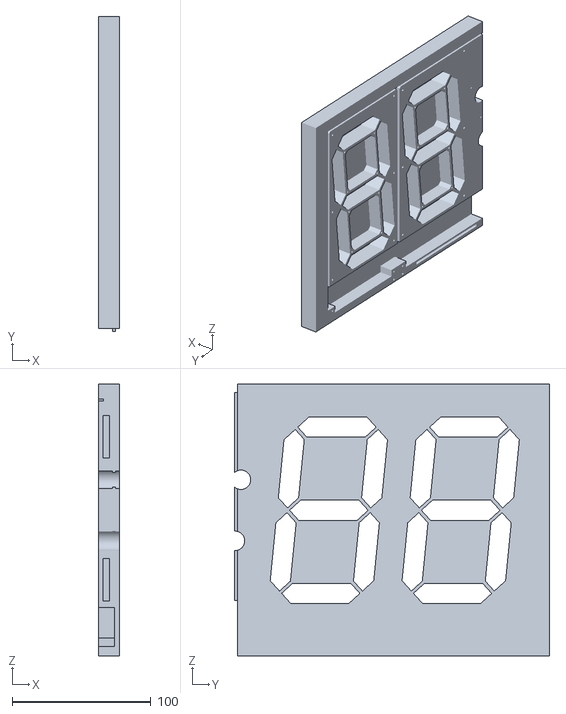
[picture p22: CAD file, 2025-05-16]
fdm/stl/digit0-1-face.stl
15.0 x 227.0 x 196.0

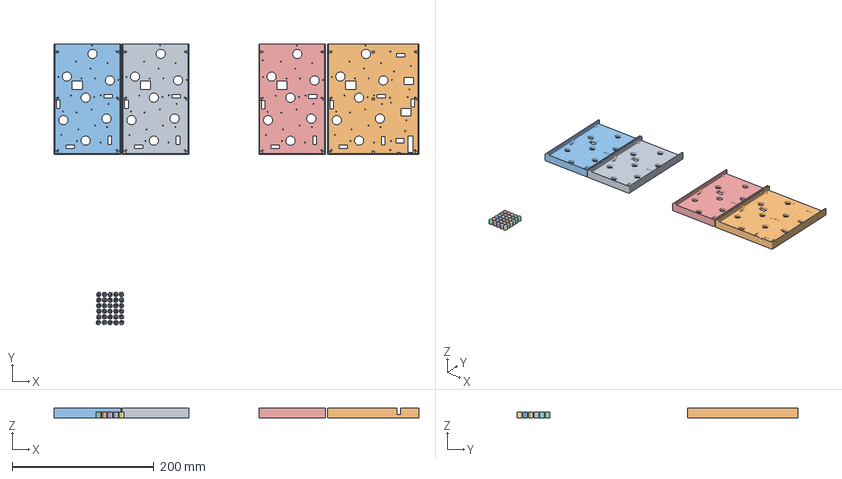
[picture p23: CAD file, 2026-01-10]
fdm/3mf/pla-smooth-black.3mf
515.1 x 396.8 x 13.6 mm
digit-back-plate.stl x 2
digit1-back-plate.stl
digit-gear10.stl x 30
digit2-back-plate.stl

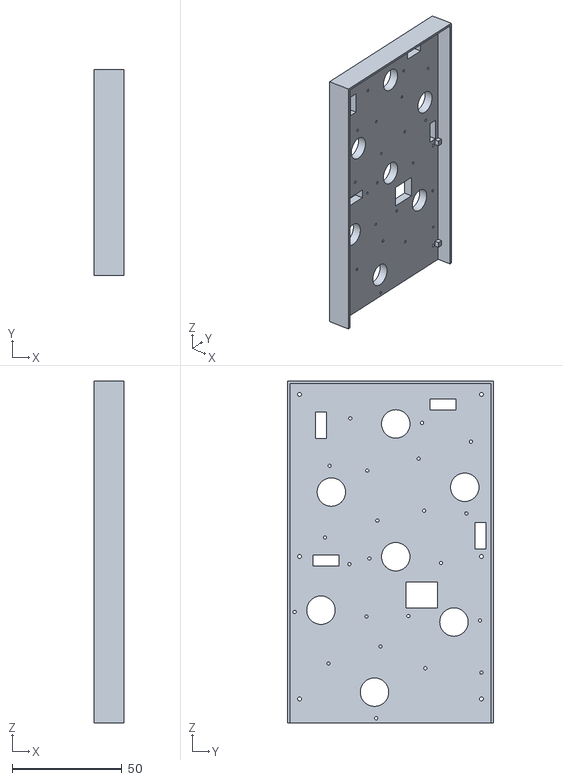
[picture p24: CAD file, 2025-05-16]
fdm/stl/digit2-back-plate.stl
13.6 x 94.2 x 156.1

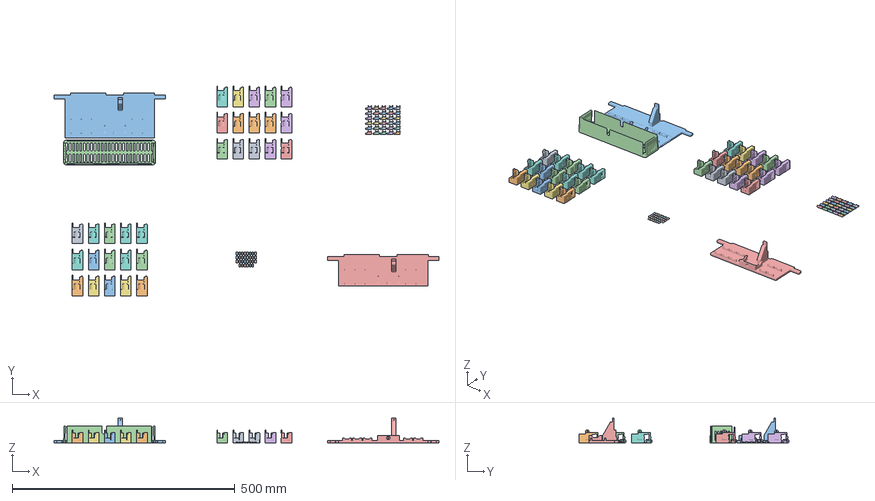
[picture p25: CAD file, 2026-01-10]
fdm/3mf/pla-smooth-white.3mf
863.7 x 470.9 x 55.9 mm
railgear-bumper.stl x 30
seg-pin.stl x 30
digit-motor-mount.stl x 30
powerbank.stl
powerbank-cover.stl
kineticdisplay-powerbank.stl

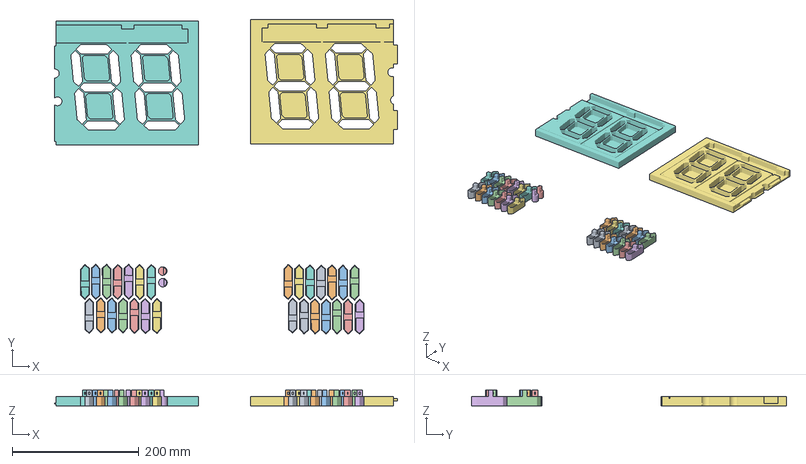
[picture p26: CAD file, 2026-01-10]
fdm/3mf/pla-textured-white.3mf
540.7 x 496.3 x 25.0 mm
seg-a.stl x 4
seg-b.stl x 4
seg-c.stl x 4
seg-d.stl x 4
seg-e.stl x 4
seg-f.stl x 4
seg-g.stl x 4
colon-seg.stl x 2
digit2-3-face.stl
digit0-1-face.stl

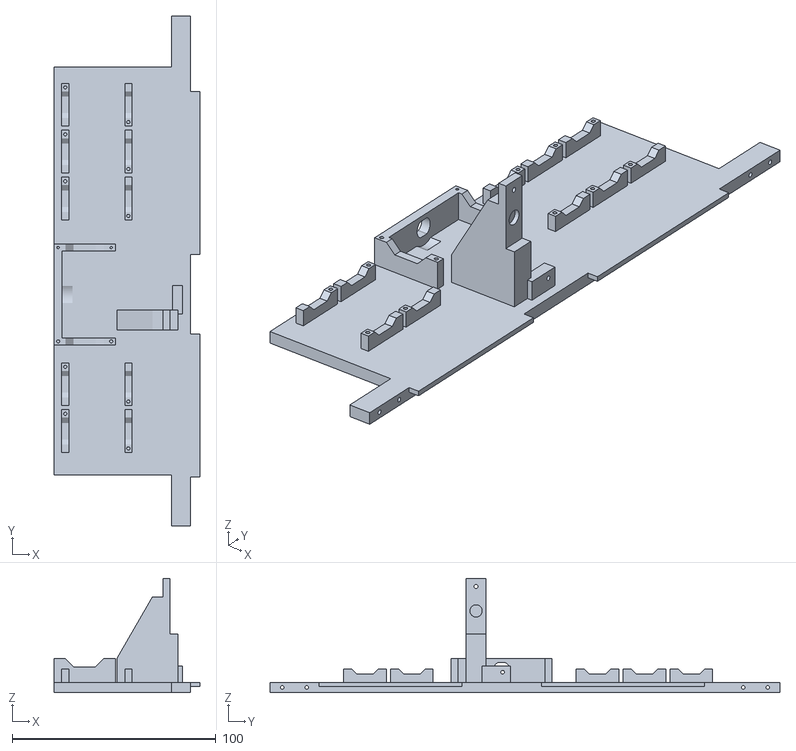
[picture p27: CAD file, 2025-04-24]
fdm/stl/powerbank-small.stl
71.5 x 250.0 x 55.9

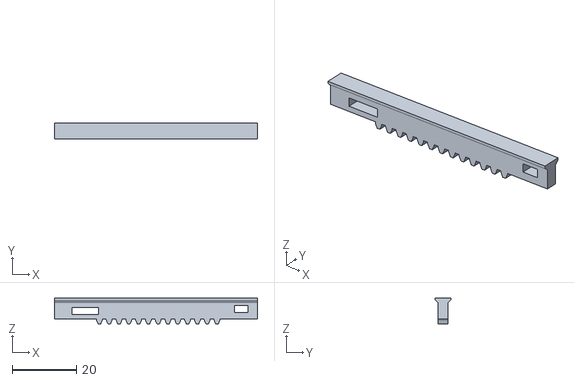
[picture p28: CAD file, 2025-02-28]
fdm/stl/rack-gear.stl
63.0 x 4.85 x 7.99

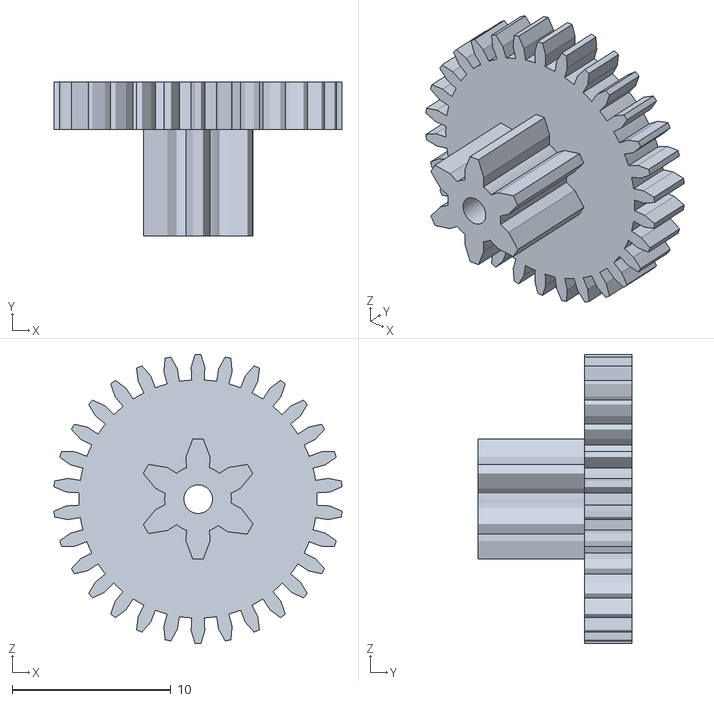
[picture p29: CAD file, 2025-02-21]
fdm/stl/digit-gear30.stl
18.1 x 9.70 x 18.2

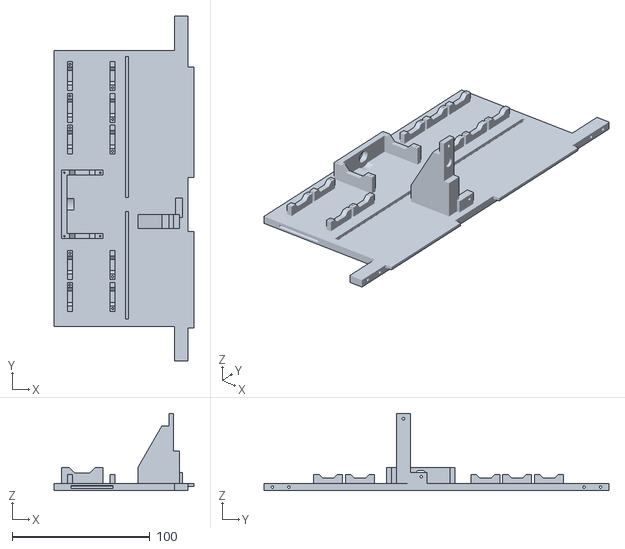
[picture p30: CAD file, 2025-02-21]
fdm/stl/powerbank.stl
101.5 x 250.0 x 55.9

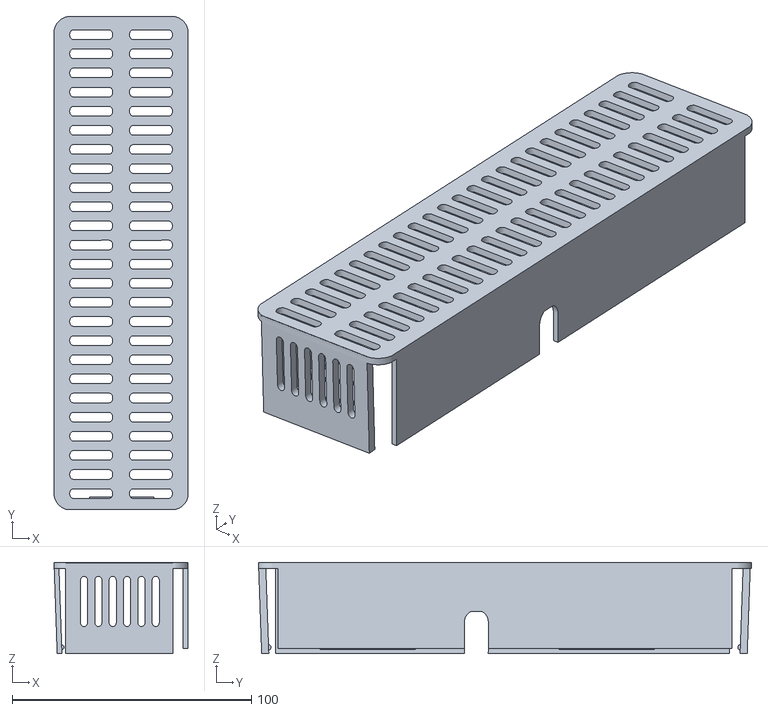
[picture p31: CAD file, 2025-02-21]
fdm/stl/powerbank-cover.stl
56.1 x 206.3 x 38.1

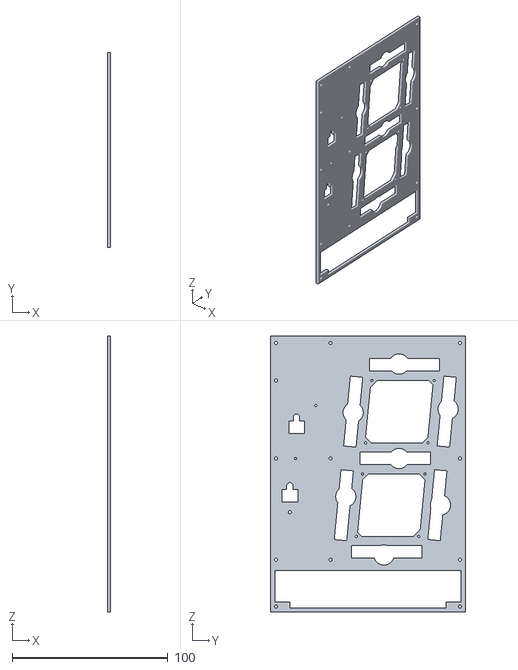
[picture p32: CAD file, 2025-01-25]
fdm/stl/digit1-gasket.stl
2.00 x 125.0 x 177.0

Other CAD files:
fdm/stl/digit2-3-face.stl
fdm/stl/digit1-back-plate.stl
fdm/stl/digit2-gasket.stl
fdm/stl/seg-d.stl
fdm/stl/colon-seg.stl
fdm/stl/digit-back-plate.stl
fdm/stl/digit-gasket.stl
fdm/stl/digit-gear10.stl
fdm/stl/digit-motor-mount.stl
fdm/stl/rackgear-bumper-gasket.stl
fdm/stl/rackgear-bumper.stl
fdm/stl/seg-a.stl
fdm/stl/seg-b.stl
fdm/stl/seg-c.stl
fdm/stl/seg-e.stl
fdm/stl/seg-f.stl
fdm/stl/seg-g.stl
fdm/stl/seg-pin.stl

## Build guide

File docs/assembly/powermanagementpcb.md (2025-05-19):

# Power Management PCB Assembly

There are several choices of power supplies available in the market. Why not simply use a retail 5V power supply? A few important reasons for building a custom power management system for the display include:

- **Stable Voltage**: A drop in voltage occurs in a poor power supply when the heavy-duty 103 electric toy motor starts up because each motor requires a high inrush of current to extend or retract the display's segments. Most retail power supplies cannot provide sufficient current, causing a dramatic voltage drop leading to instability. The power supply setup in this section ensures the components receive a consistent 5V power, preventing malfunctions or damage to the more sensitive electronic components like the microcontrollers and sensors.
- **Current Requirements**: The display has colons with two motors and four digits, each with seven independent electric motors. There can be up to five electric motors running simultaneously to extend or contract the segments or colons. Note there are also additional power requirements for lighting the LEDs. The power system you'll build in this section provides sufficient current to power all motors, sensors, and controllers simultaneously.
- **Safety**: Protects the system from overvoltage, short circuits, or power surges.
- **Customization**: Tailors the power supply to meet the specific needs of the kinetic display's design and components.
- **Efficiency**: Reduces energy loss and improves the overall performance of the display. An old-school coil-driven relay is used to shut off power to the digits when in low-power mode and not active. There are other ways to accomplish the same functionality with solid-state relays or a FET. However, the display is kinetic by design, and the use of a coil relay enhances its sound, feel, and aesthetics.

## Prerequisites

- [Fabrication of the power management PCB](../createandorder/pcb.md).
- 3D print the display stand. You have two options: `powerbank.stl` or `powerbank-small.stl`. Print the `powerbank.stl` and `powerbank-cover.stl` if you have household animals that might have access to the back of the display. Print `powerbank-small.stl` to keep a lower profile of the back of the display. Mounting `powerbank.stl` and `powerbank-small.stl` is the same for both sizes.

***Table of components***

| Quantity | Component | Image |
| :--: | :--- | :-----: |
| 2 | 2 Pin PCB Mount Screw Terminal Block Connector Straight Pin | component-5 |
| 1 | 3 Pin PCB Mount Screw Terminal Block Connector Straight Pin | component-23 |
| 2 | 4 Pin PCB Mount Screw Terminal Block Connector Straight Pin | component-24 |
| 1 | SONGLE SRS-05VDC-SL 05VDC-SL 4100 Blue 5V 6PIN Power Relay | component-25 |
| 1 | 1N4001 Diode, standard, 1A, 50V, DO-41 | component-26 |
| 1 | S8050 TO-92 TH PNP Transistor | component-20 |
| 2 | 1K ohm 0805 Resistor 1/4w Metal Film Fixed Resistor | component-22 |
| 1 | 2.1mm Barrel Jack 5.5x2.1mm Female DC Power Jack 2.1 X 5.5mm DC Jack Connector 6V 9V 12V DC Jack Panel Mount | component-27 |
| 10M | White 28 AWG Gauge Flexible Silicone Rubber Electric Wire | component-28 |
| 10M | Black 28 AWG Gauge Flexible Silicone Rubber Electric Wire | component-29 |
| 50cm | (optional) 28 AWG Gauge heat shrink | component-30 |
| 4 | M1.7x6mm Cross Round Head with Washer Self Tapping Screw 304 Stainless Steel Screws | component-32 |

***Table of tools***

| Required | Tool | Image |
| :---: | :--- | :---: |
| Yes | Soldering station | tool-4 |
| Yes | 0.8mm 1.76oz RoHS flux core solder | tool-1 |
| Yes | Mini flush cutters | tool-6 |
| Yes | Isopropyl Alcohol | tool-3 |
| Yes | Cotton Facial Pads | tool-2 |
| No | Heat gun | tool-15 |

## Power Management PCB Components

In this section, you'll assemble the power management system PCB.

Top view of the power management PCB:  
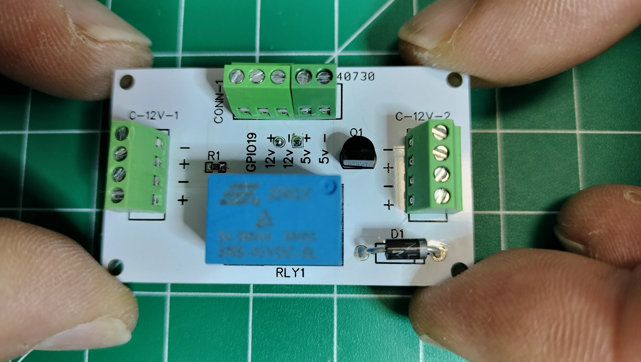
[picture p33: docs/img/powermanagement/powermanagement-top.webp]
powermanagement-top
  
Bottom view of the power management PCB:  
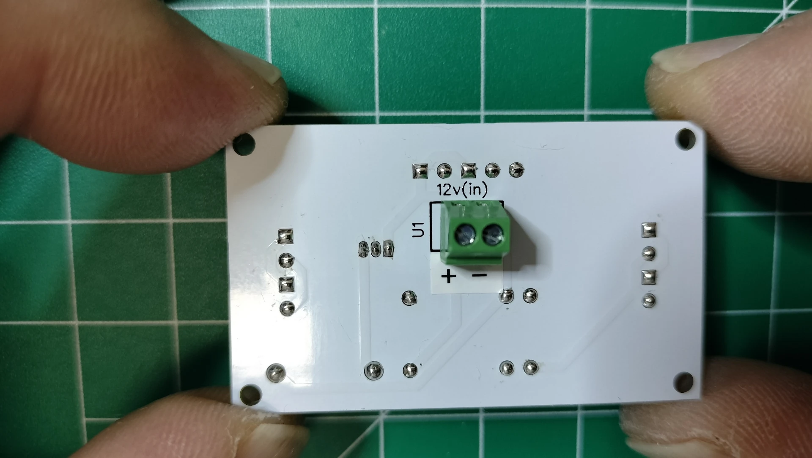
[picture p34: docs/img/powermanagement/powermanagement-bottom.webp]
powermanagement-bottom


1. Following the picture below on the TOP side of the PCB, solder the `1kΩ 0805` surface mount resistor onto `R1`.  
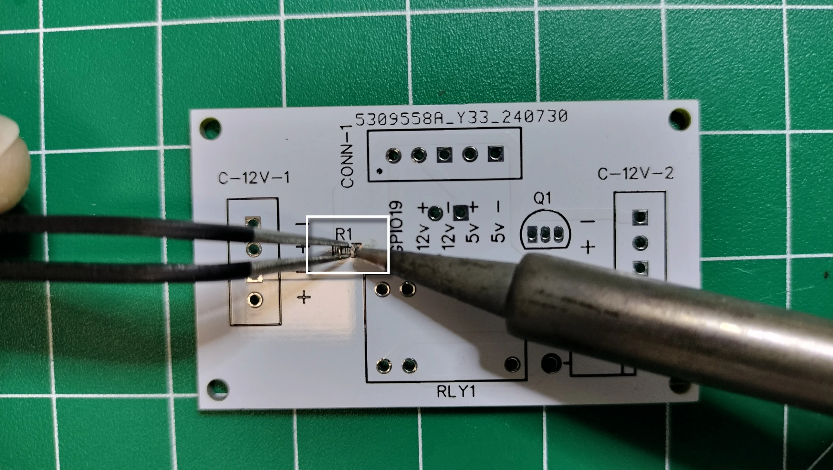
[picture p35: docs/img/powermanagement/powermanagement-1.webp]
powermanagement-1
   
1. Following the picture below on the TOP side of the PCB, solder the `s8050` through-hole transistor into `Q1`. Be sure to align the pins according to the silk screen outline.  
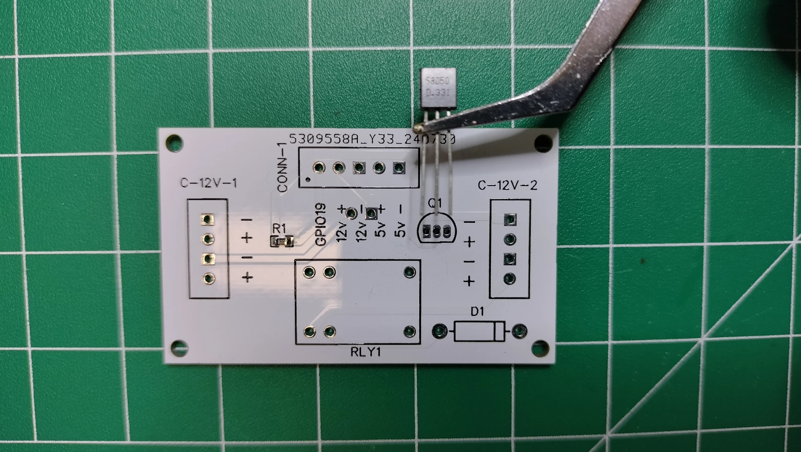
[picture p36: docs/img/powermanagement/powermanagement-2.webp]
powermanagement-2
   
1. Following the picture below on the TOP side of the PCB, solder the `1N4001` diode into `D1`. Be sure to align the cathode band with the silk screen outline.  
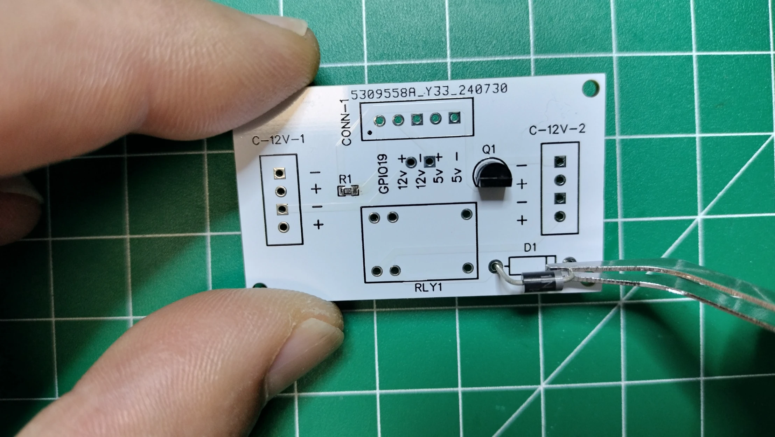
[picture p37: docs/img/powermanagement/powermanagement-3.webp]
powermanagement-3
   
1. Following the picture below on the TOP side of the PCB, solder the 6 pins of the Songle relay into `RLY1`.  
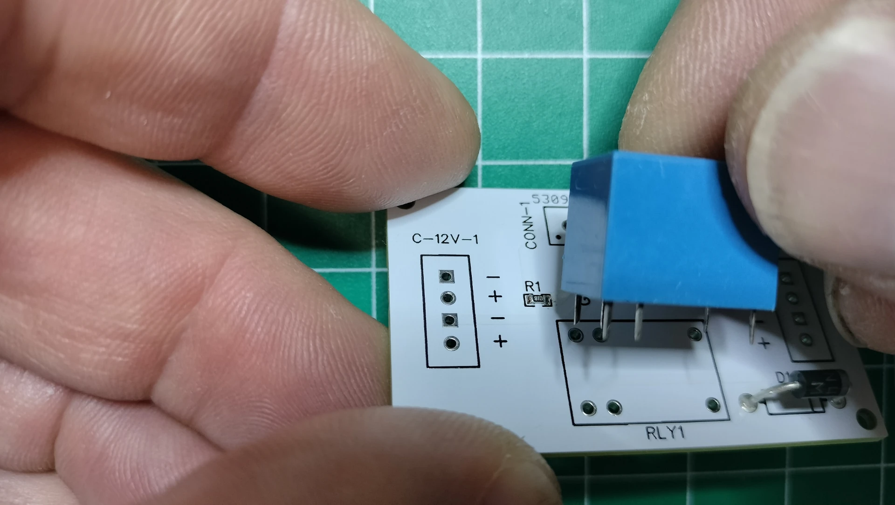
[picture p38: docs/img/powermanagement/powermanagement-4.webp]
powermanagement-4
   

## Power Management PCB Block Connectors

Top view of the power management PCB with arrows pointing in the direction of the connected wire.  
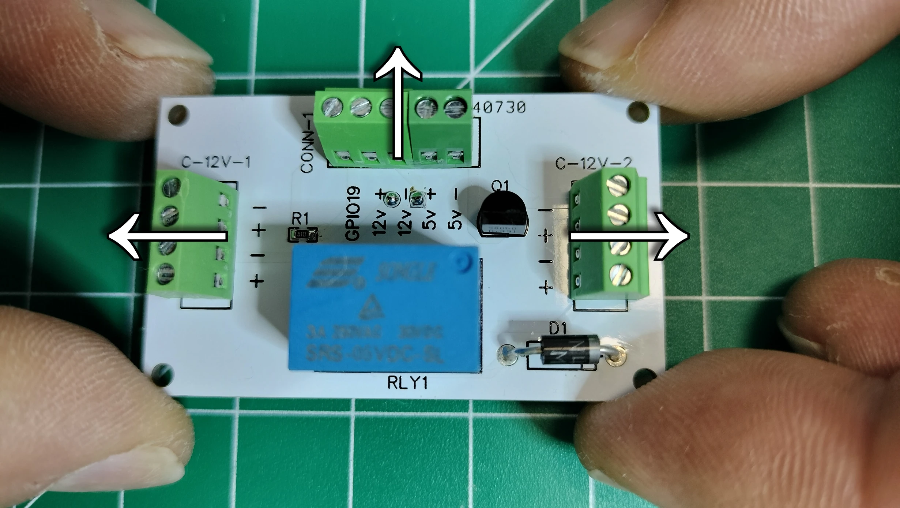
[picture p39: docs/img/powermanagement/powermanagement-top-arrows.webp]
powermanagement-top-arrows


Bottom view of the power management PCB with the arrow pointing in the direction of the [Barrel Jack Panel Mount](#barrel_jack_panel_mount) wires.

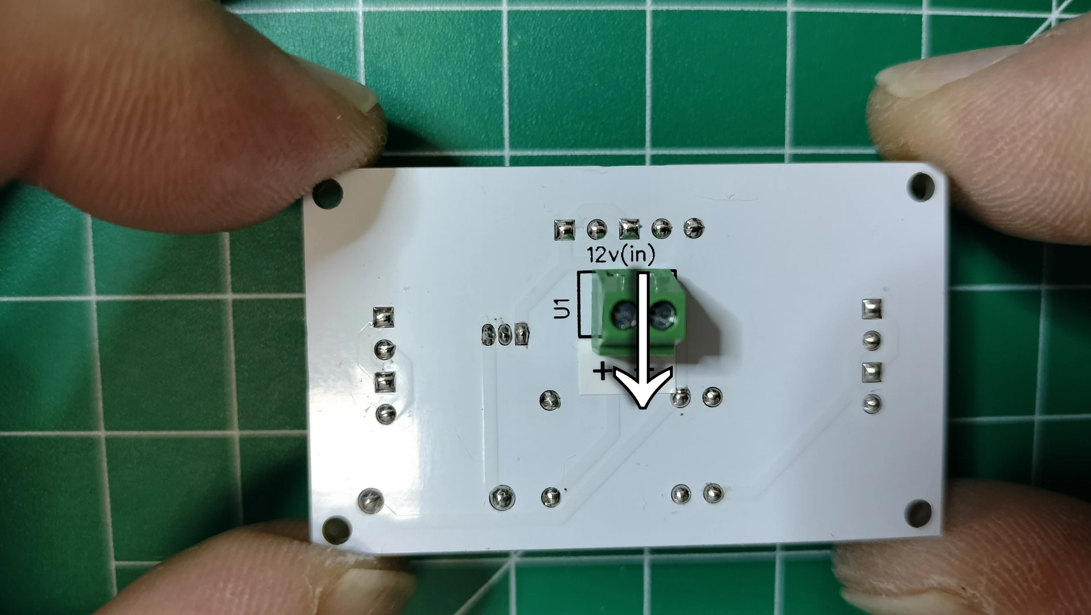
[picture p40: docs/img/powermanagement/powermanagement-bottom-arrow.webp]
powermanagement-bottom-arrow


1. Following the picture below on the TOP side of the PCB, hold the PCB so the silk screen `C-12V-1` is to your left. Solder the 4 pin terminal block connector into the `C-12V-1` through holes so the connection to the wires faces out to the left.  
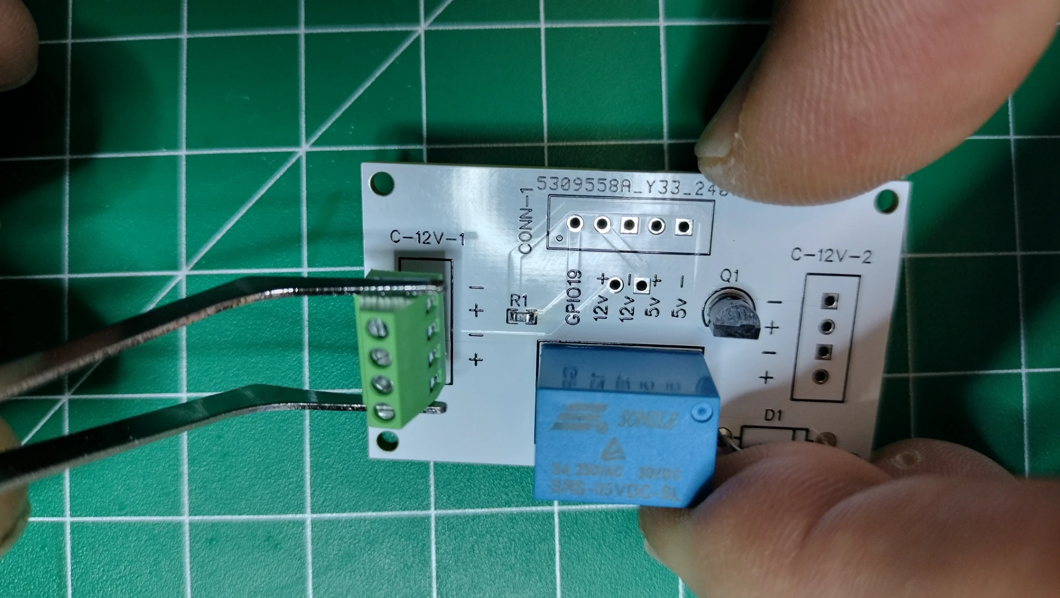
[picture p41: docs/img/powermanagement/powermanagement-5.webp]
powermanagement-5
   
1. Following the picture below on the TOP side of the PCB, hold the PCB so the silk screen `C-12V-2` is to your right. Solder the 4 pin terminal block connector into the `C-12V-2` through holes so the connection to the wires faces out to the right.  
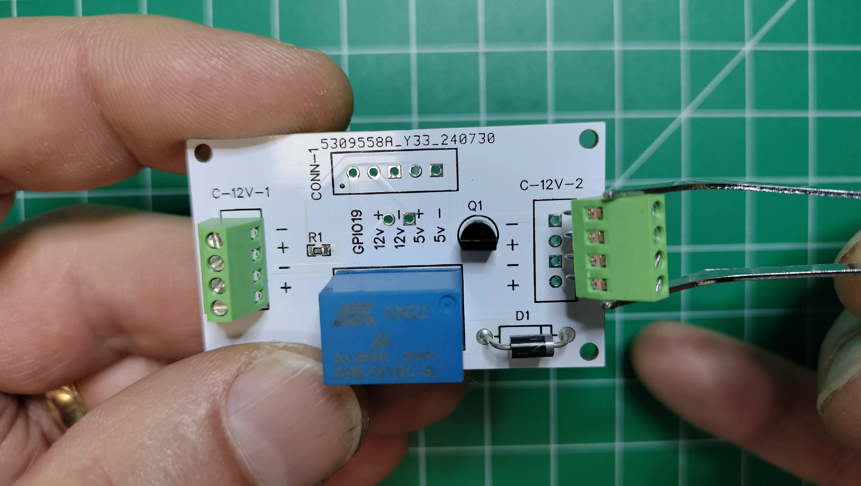
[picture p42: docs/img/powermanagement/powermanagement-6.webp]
powermanagement-6
   
1. Following the picture below on the TOP side of the PCB, hold the PCB so the silk screen `CONN-1` is to your left. Solder the 2 pin terminal block connector into the `5v+ 5v-` through holes of the `CONN-1` silk screen so the connection to the wires faces out to the left.  
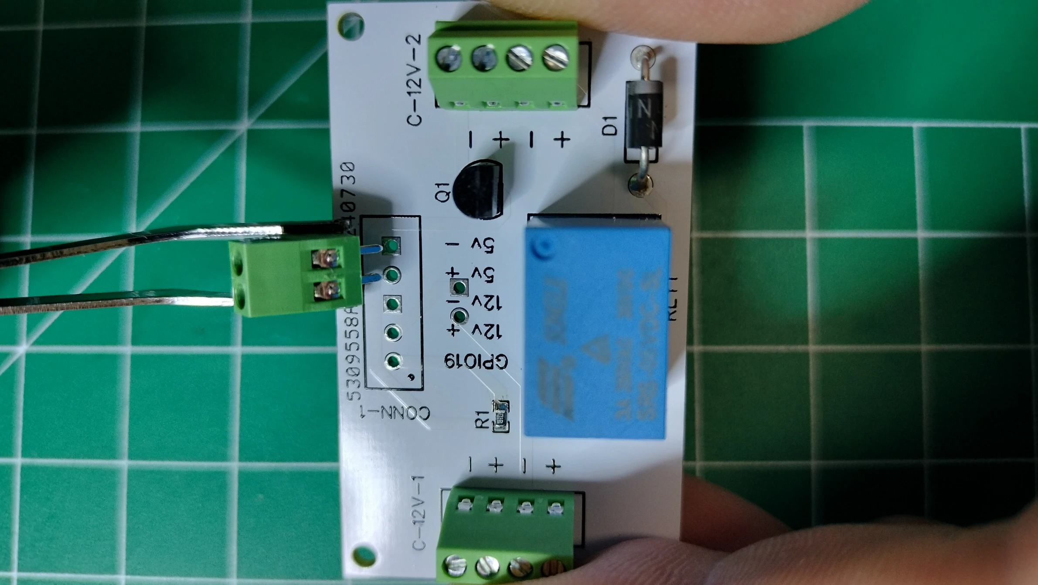
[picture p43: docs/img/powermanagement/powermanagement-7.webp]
powermanagement-7
   
1. Following the picture below on the TOP side of the PCB, continue to hold the PCB so the silk screen `CONN-1` to your left. Solder the 3 pin terminal block connector into the `GPIO19 12v+ 12v-` through holes of the `CONN-1` silk screen so the connection to the wires faces out to the left.  
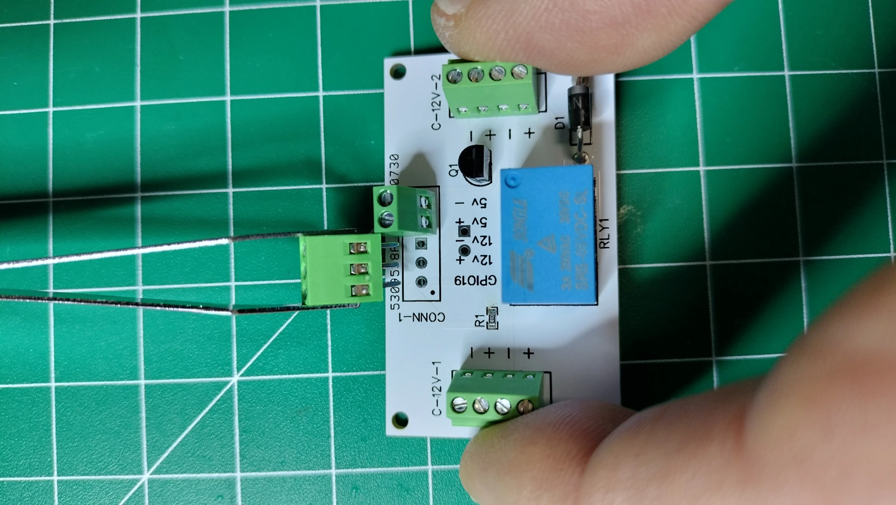
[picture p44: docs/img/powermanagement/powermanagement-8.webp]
powermanagement-8
   
1. Following the picture below on the BOTTOM side of the power management PCB, solder the two pins of the terminal block connector into the through holes marked as `12v(in)`.  
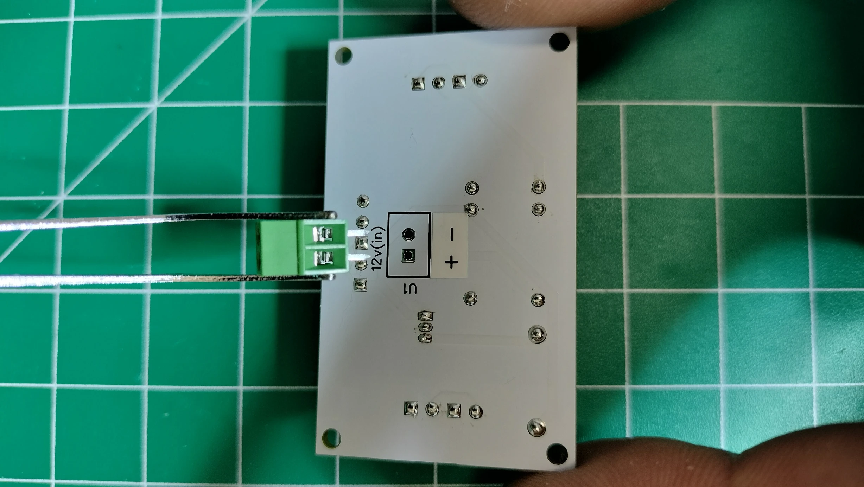
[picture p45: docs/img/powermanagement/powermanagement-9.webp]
powermanagement-9
   

## Barrel Jack Panel Mount

1. Cut a black and white 28 AWG wire 4cm in length.  
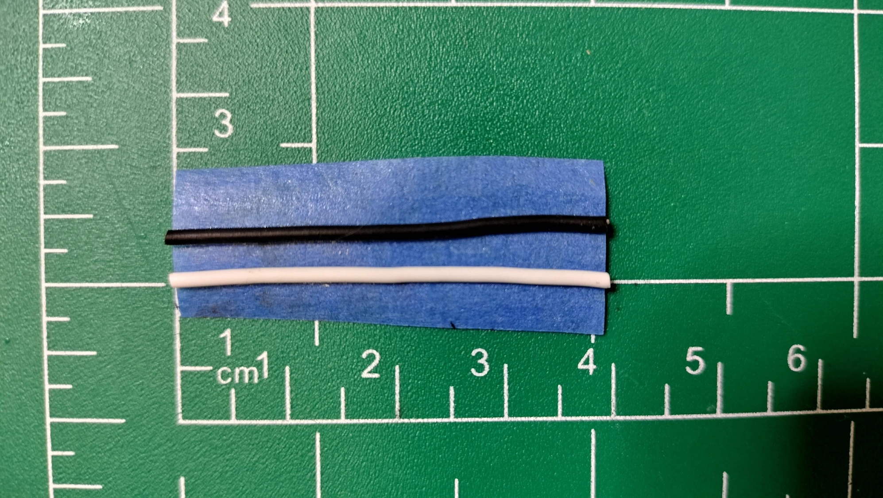
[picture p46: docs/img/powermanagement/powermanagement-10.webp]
powermanagement-10
   
1. Strip about 3mm off the ends of each wire, then tin the stripped ends with a bit of solder.  
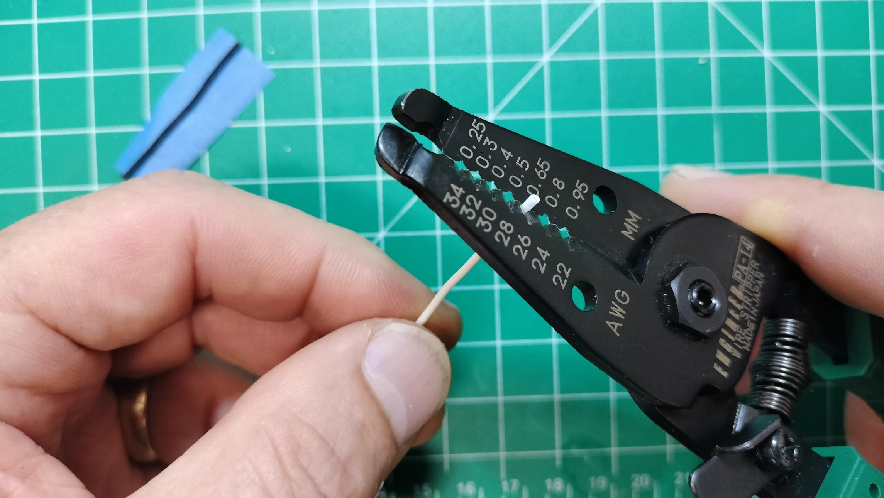
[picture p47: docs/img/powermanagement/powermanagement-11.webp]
powermanagement-11
   
1. Using a multimeter, locate the positive and negative pins on the barrel jack. In this case, the longer pin is negative.  
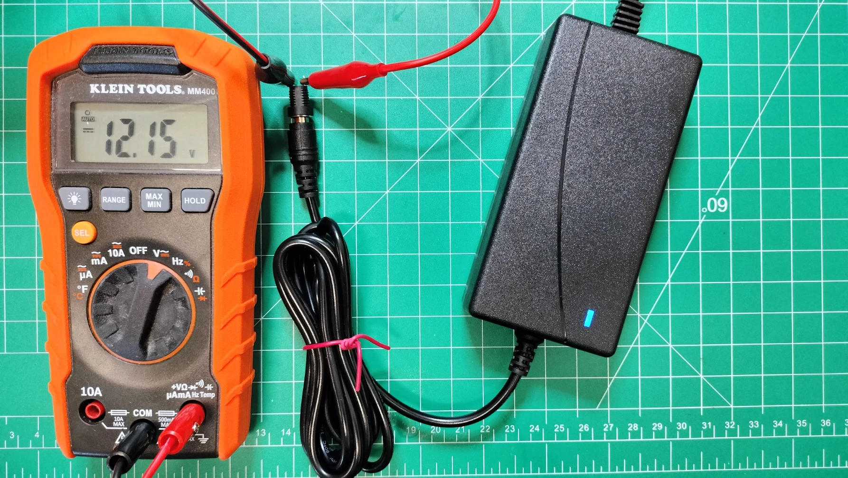
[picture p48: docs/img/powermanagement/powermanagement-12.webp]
powermanagement-12
   
1. Based on the results from the previous step, solder the white wire onto the positive pin and black onto the negative pin.  
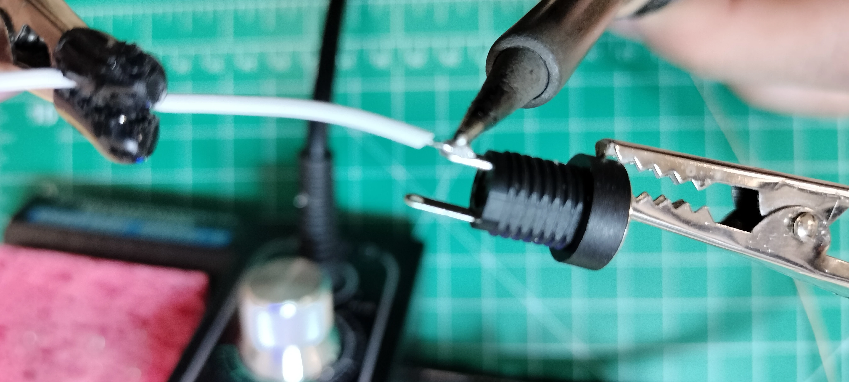
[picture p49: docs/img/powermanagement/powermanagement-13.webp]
powermanagement-13
   
1. Add heat shrink to protect exposing the soldered pin locations. Wrap the exposed soldered pin with a piece of electrical tape if you don't have any heat shrink.  
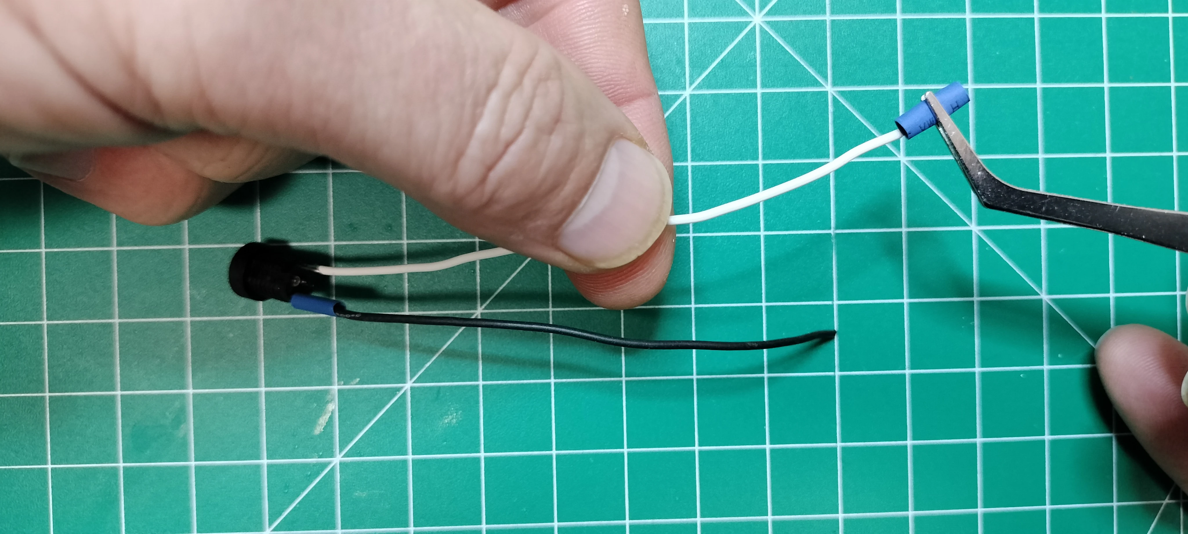
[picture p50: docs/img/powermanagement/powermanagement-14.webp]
powermanagement-14
   
1. Secure the heat shrink with a heat gun.  
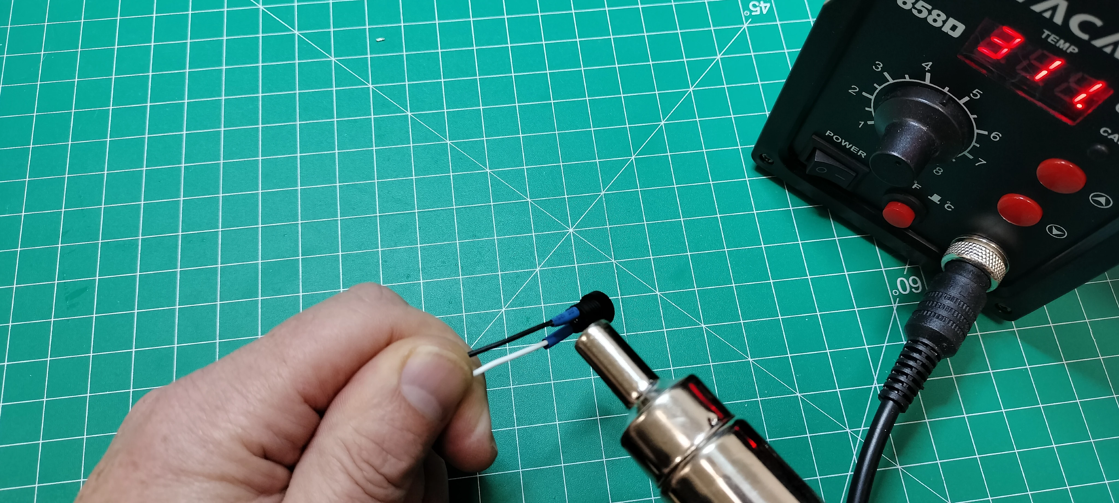
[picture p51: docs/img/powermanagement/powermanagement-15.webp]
powermanagement-15
   
1. Insert the barrel jack into the display stand as shown in the picture below. Note the barrel jack has opposing flat sides that will need to align with the display stand hole.  
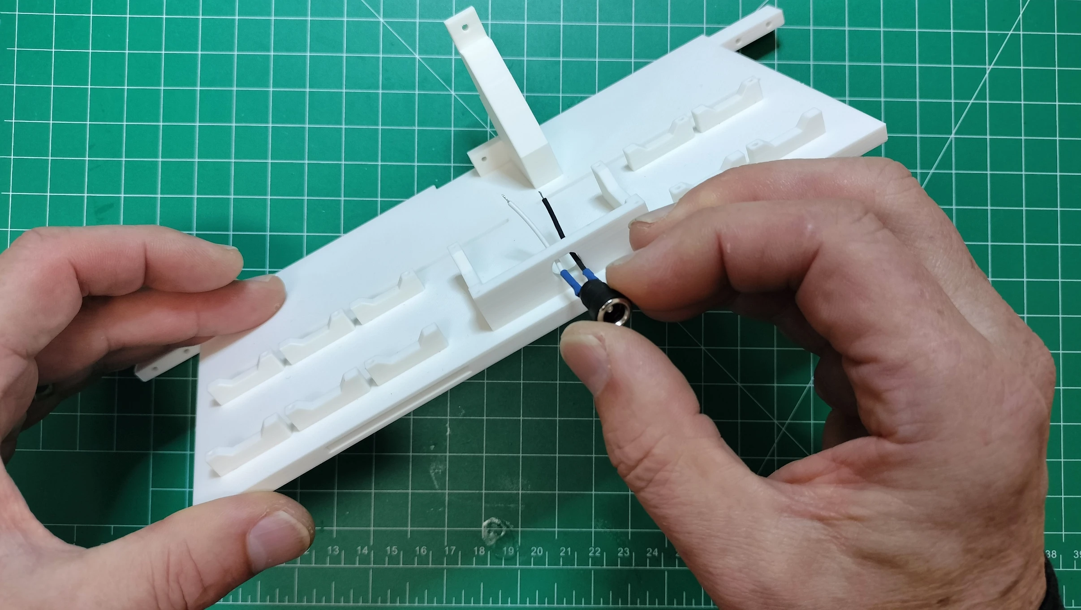
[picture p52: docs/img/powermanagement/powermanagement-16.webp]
powermanagement-16
   
1. Add the jack nut onto the backside of the barrel jack. Tighten with a wrench so the nut is snug. Don't over tighten as you may damage the stand.  
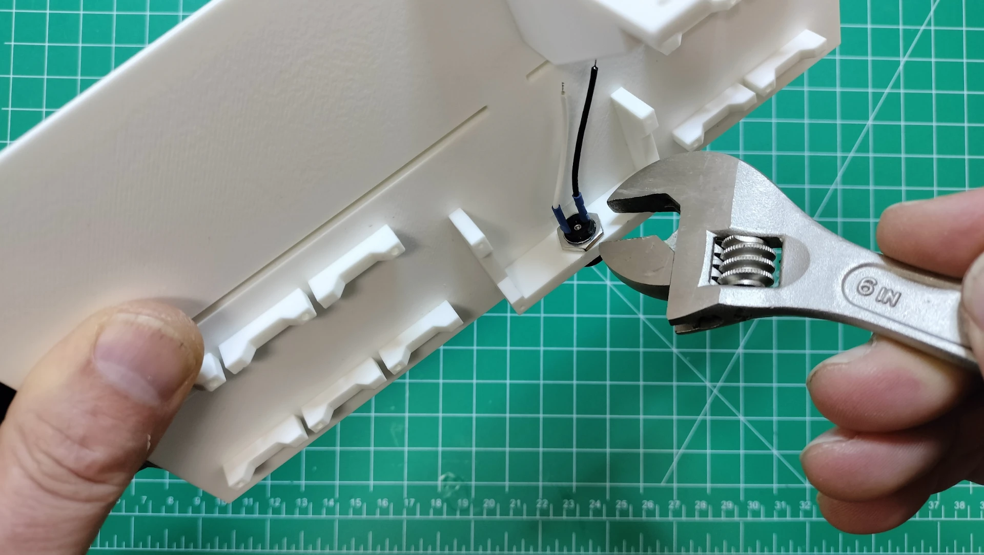
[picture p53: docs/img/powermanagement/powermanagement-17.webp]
powermanagement-17
   
1. Position the bottom side of the power management PCB so the 2 pin terminal block connector is facing toward the mounted barrel jack. Insert and tighten the white wire to the positive (+) terminal and the black wire to the negative (-) terminal.  
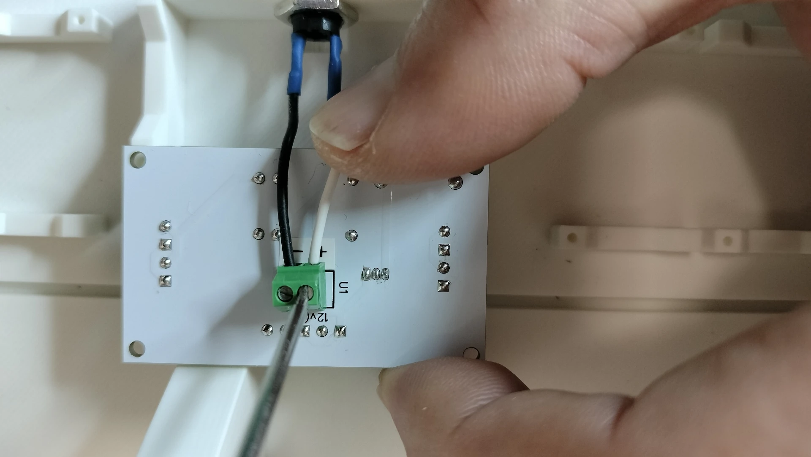
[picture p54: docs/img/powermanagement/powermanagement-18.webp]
powermanagement-18
   
1. Use two M1.7x6mm self tapping screws to tack the PCB down as later you'll need to remove the PCB to route the wiring.  
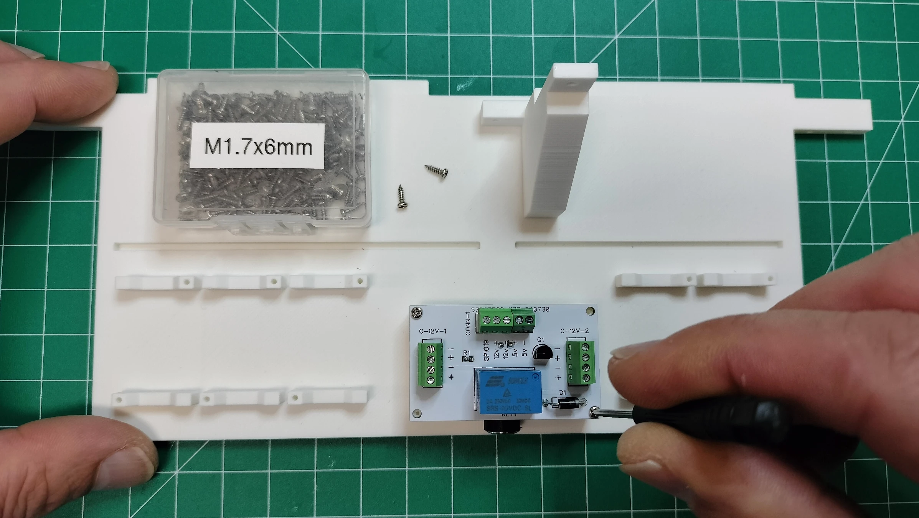
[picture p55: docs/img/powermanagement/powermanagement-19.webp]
powermanagement-19
   
1. Plug the 12v power supply into the barrel jack. Verify the 12v `+` and `-` voltage by placing the probes from a multimeter onto the `+` and `-` terminals found on the 4 pin connectors titled `C-12V-1` and `C-12V-2`.  
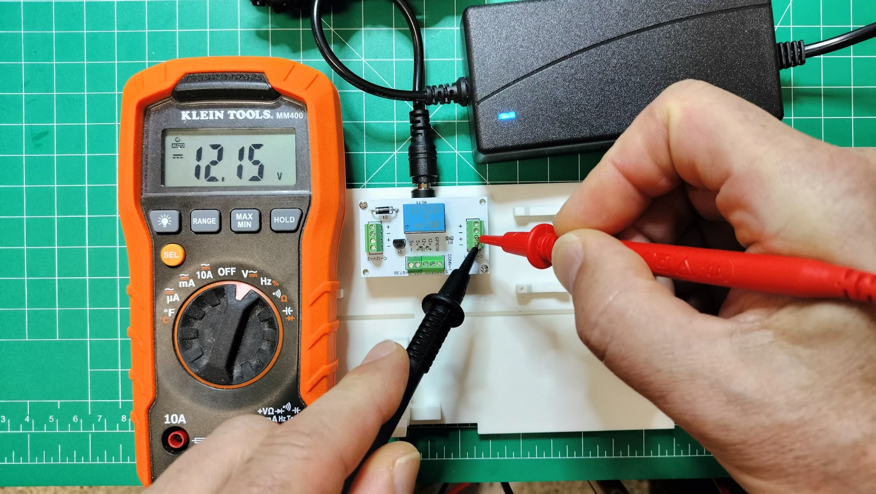
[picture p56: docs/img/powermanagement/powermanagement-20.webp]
powermanagement-20
   

!!! warning
    Verifying the 12v `+` and `-` voltage with a multimeter is an important step to ensure the correctness of your connections. If you discover the `+` and `-` are reversed, then change the connections from the barrel jack and re-verify using your multimeter.

## Schematic

The power management PCB is designed to provide stable and sufficient power to the kinetic display's motors, LEDs, and sensors. It incorporates protection mechanisms (diode, relay), current regulation (resistor, transistor), and secure connections (terminal blocks, barrel jack). The power management schematic with the buck converter modules ensure the system operates efficiently and safely under varying load conditions.

### Key Components

1. **1kΩ Resistor (R1)**:
    Used to limit current flow to the base of the transistor.
1. **S8050 PNP Transistor (Q1)**:
    Acts as a switch used to control the relay.
1. **1N4001 Diode (D1)**:
    Protects the circuit from reverse polarity or voltage spikes due to the coils in the relay.
1. **Songle Relay (RLY1)**:
    A mechanical switch controlled by an electrical signal. It is used to switch high-current loads (e.g., motors) on and off safely.
1. **PCB Mount Screw Terminal Blocks**:
    Provide secure connections for external wires to the PCB. These are used for power input and output connections.
1. **Barrel Jack Connector**:
    Used to connect the external 12V power supply to the PCB.

### Circuitry Explanation

1. **Power Input**. The 12V power supply is connected to the barrel jack. The positive and negative terminals are routed to the PCB through the terminal block connectors.
1. **C-12v-1** and **C-12v-2**. Terminal block connector through holes that route the incoming 12v to the assigned buck converter module. When the relay is switched off, the 12v power is cut to the buck converter modules.
1. **Relay Control**. The relay (RLY1) is controlled by the transistor (Q1). When the transistor is activated by the Raspberry Pi Pico W 2040 GPIO19 pin, it allows current to flow through the relay coil, switching the relay and enabling power to the connected load.
1. **Voltage Regulation**. The circuit routing 12v to the buck converter modules ensures stable 5V output for sensitive components like the micro controllers and sensors. This is critical to prevent malfunctions caused by voltage drops during high-current motor operations.
1. **Protection**. The diode (D1) protects the circuit from voltage spikes generated by the relay coil when it is de-energized. This prevents damage to other components.
1. **Current Distribution**. The terminal blocks distribute power to various parts of the display, including the microcontrollers, motors, LEDs, and sensors. The 4-pin connectors (`C-12V-1` and `C-12V-2`) handle the 12V power.
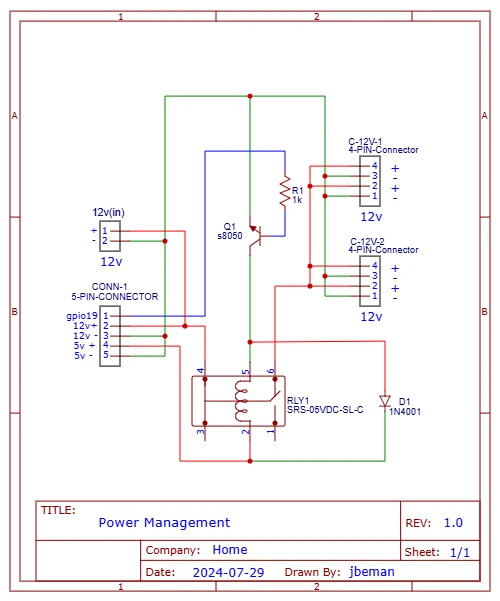
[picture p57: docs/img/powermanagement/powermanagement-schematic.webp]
powermanagment-schematic


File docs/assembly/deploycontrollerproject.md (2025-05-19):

# Deploy the Conductor Project to the Conductor PCB

In this guide you will upload code from the **conductor** folder on your computer to your Raspberry Pi Pico W 2040.

## Prerequisites

- Completed the assembly and soldering of the [conductor PCB](controllerpcbassembly.md).
- Created a fork of the Kinetic-Display GitHub repository. See [Software and Microcontroller Preparation](../prerequisitesoftware.md).
- Deployed the digit and controller directories. Also, see [Software and Microcontroller Preparation](../prerequisitesoftware.md).

## Configure and Deploy the Conductor Project

1. Connect your computer to the conductor PCB Pico W 2040 as described in [Verify Micropython on your Raspberry Pi Pico](../prerequisitesoftware.md).
1. Open VS Code and follow the steps below:
      - **(A)** Select **File -> Open Folder...**.
      - **(B)** Navigate to the **deploy/conductor** folder you deployed during step 4 in the section [Fork and Clone the Repository](../prerequisitesoftware.md).
      - **(C)** Click the "Select Folder" button.  
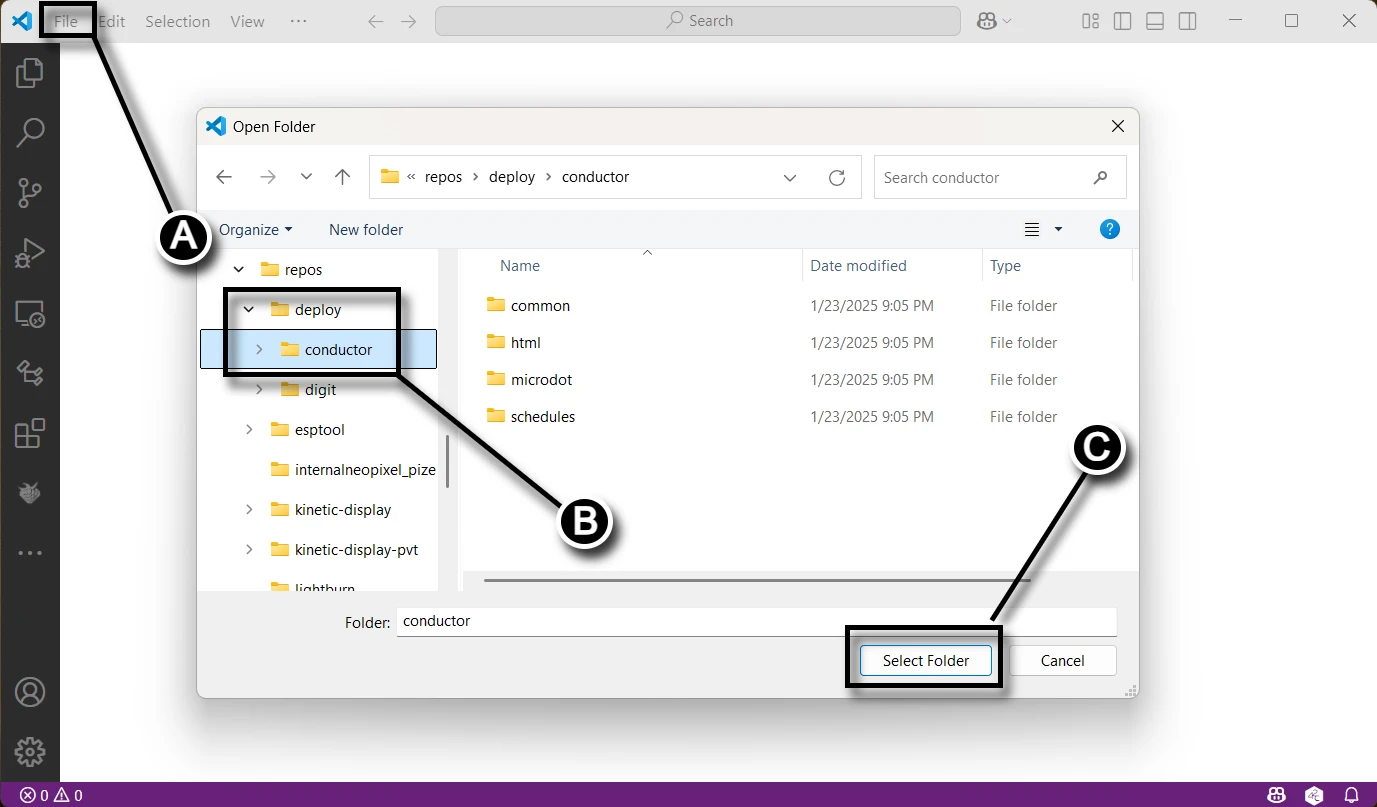
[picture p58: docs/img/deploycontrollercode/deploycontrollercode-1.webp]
   
1. Open the `main.py` file and make the following changes:
      - **(A)** Comment out the call to the `loop()` function.
      - **(B)** Uncomment the `manual()` function.
      - **(C)** Rename the `main.py` file to `_main.py`.  
   Don't forget to save the file after making these changes.  
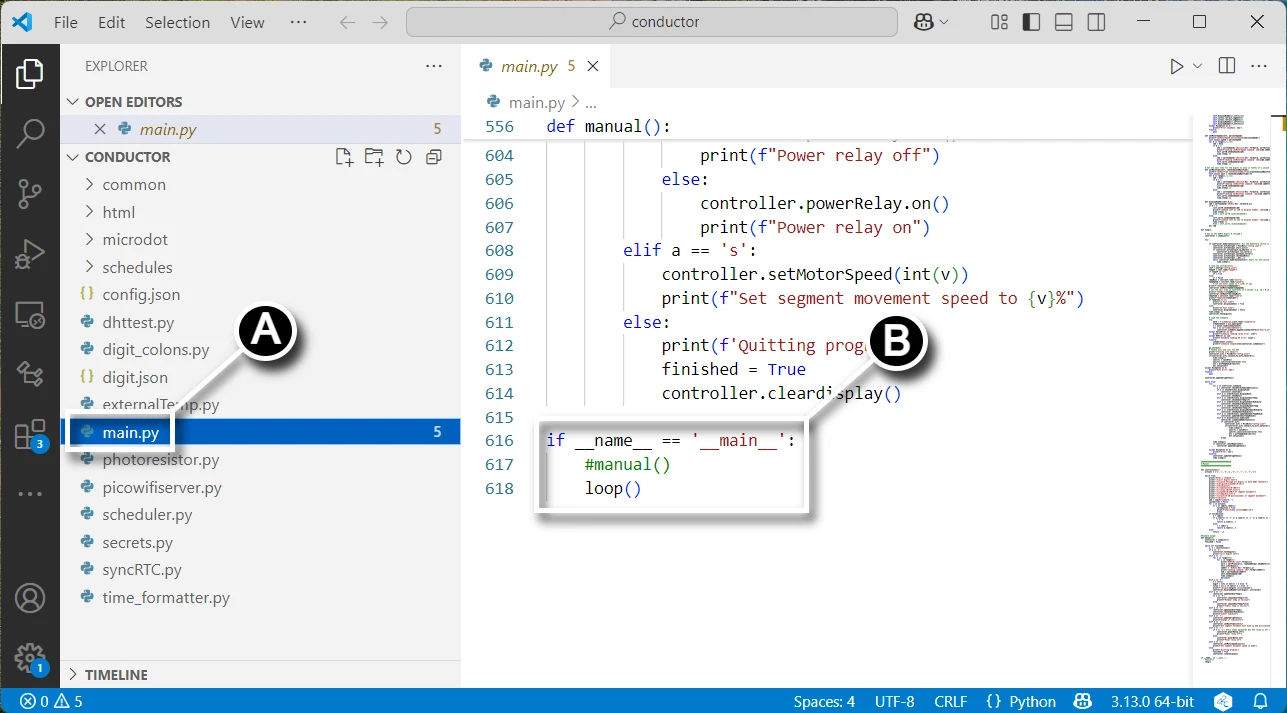
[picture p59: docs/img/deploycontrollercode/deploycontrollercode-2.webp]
deploycontrollercode-2
   
1. Create a new terminal in VS Code:
      - **(A)** Click the ellipsis (`...`) in the terminal pane.
      - **(B)** Select **Terminal -> New Terminal** from the submenu.  
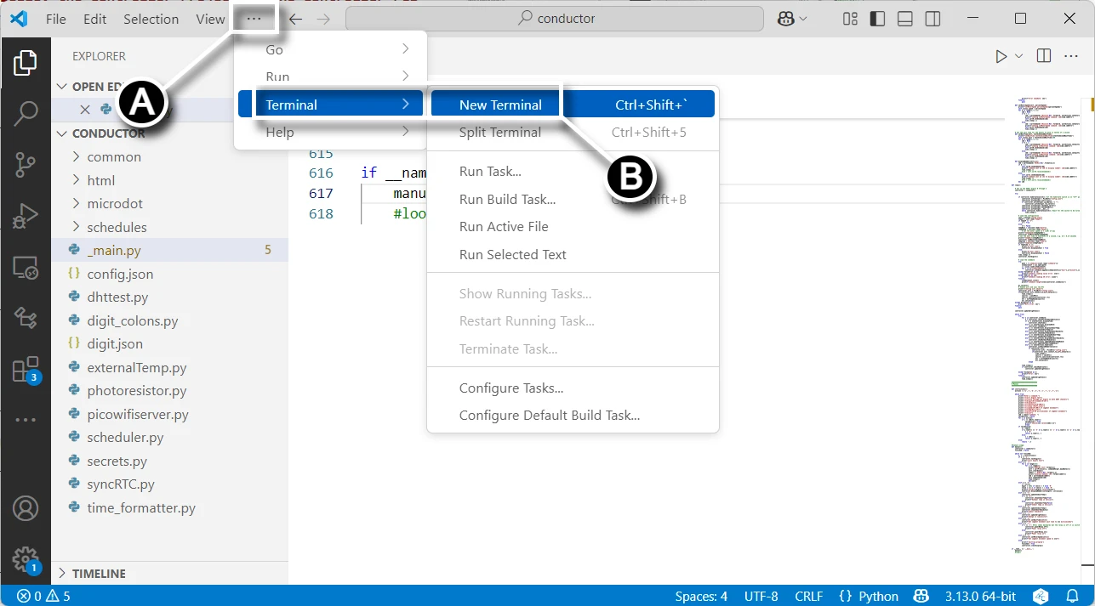
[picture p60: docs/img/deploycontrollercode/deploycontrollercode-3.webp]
deploycontrollercode-3
   
1. Connect your computer's USB port to the Raspberry Pi Pico W 2040 as shown below:  
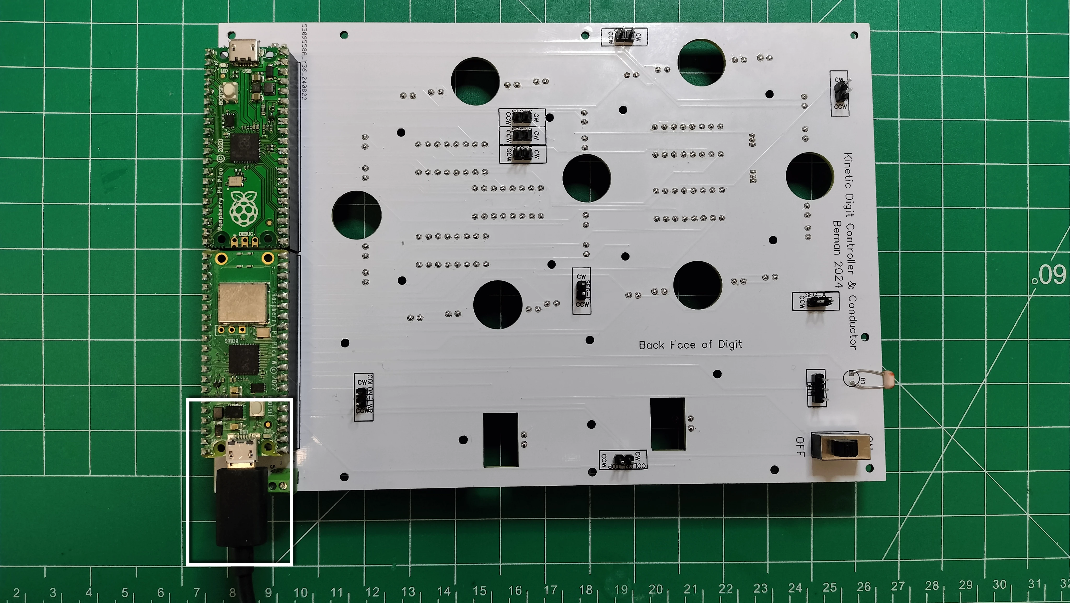
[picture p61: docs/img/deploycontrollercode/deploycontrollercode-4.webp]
deploycontrollercode-4
   
1. In the terminal pane:
      - **(A)** Select the drop-down menu.
      - **(B)** Click the **MicroPico vREPL** submenu item.  
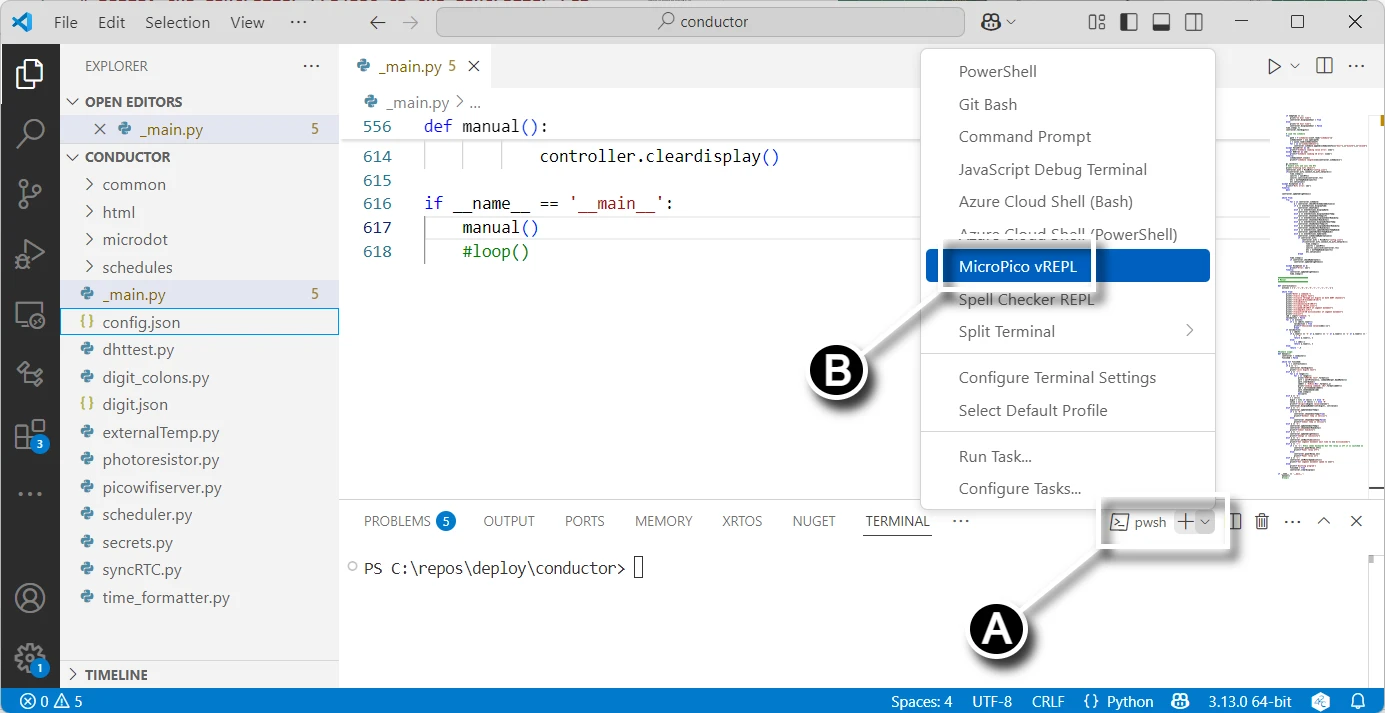
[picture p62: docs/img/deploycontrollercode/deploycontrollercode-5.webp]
deploycontrollercode-5
   
1. Upload the project to the Pico:
      - **(A)** Click **All Commands** on the [status bar](https://code.visualstudio.com/api/ux-guidelines/status-bar).
      - **(B)** In the Command text field, type "**Upload**" after "**> MicroPico:** ".
      - **(C)** Select the dropdown **MicroPico: Upload project to Pico**.  
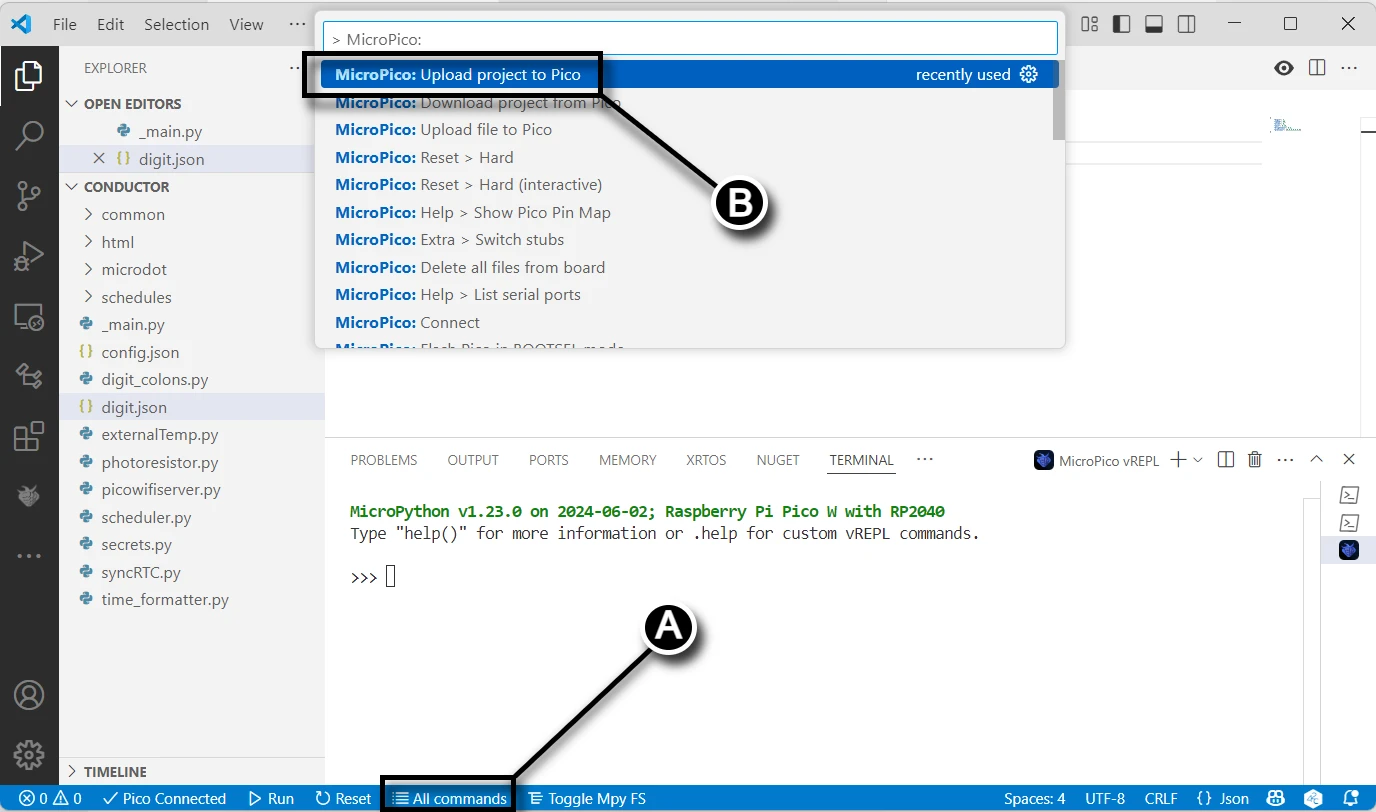
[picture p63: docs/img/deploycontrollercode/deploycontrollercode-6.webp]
deploycontrollercode-6
   

## Configuration Options

The Kinetic Display can be configured through the web interface after connection to Wi-Fi. The following settings are available:

- **Time Format**: 12-hour or 24-hour time format (setting: `time`)
- **Motor Speed**: Controls the speed of segment movements (setting: `speed`)
- **Wait Time**: Delay between segment movements in milliseconds (setting: `wait`)
- **Temperature Unit**: Celsius or Fahrenheit (setting: `tempCF`)
- **Schedule**: The event schedule file to use (setting: `schedule`)
- **Digit Test at Startup**: Enable or disable the digit test animation when the display starts up (setting: `enable_test_digits`)
  - Set to `true` to enable the digit test (default)
  - Set to `false` to disable the digit test

Disabling the digit test at startup can be useful in environments where the mechanical noise of the segment movements might be disruptive, or when you want the display to start showing the time immediately.

Congratulations on successfully uploading the code to the conductor's Raspberry Pi Pico W!

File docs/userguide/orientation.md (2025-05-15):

# User Guide - Orientation

This guide provides a visual and descriptive overview of the Kinetic Display, helping you identify and understand each of its key components and features. You'll learn how to recognize the display's front, top, and back, and discover the function of each labeled part. The main sections include:

- **Front of Display:** Learn about the digit layout, segment actions, and how the display shows time, date, temperature, humidity, and digit styles.
- **Top of Display:** See the stand options and how the top profile is designed for stability and protection.
- **Back of Display:** Identify all major components, including sensors, microcontrollers, actuators, and power connections, with clear explanations of their roles.

By the end of this guide, you'll be able to confidently orient the Kinetic Display, understand its capabilities, and know where to find each important feature for setup, troubleshooting, or customization.

---

## Front of Display

Refer to the diagram below to identify the main features on the front of the display:

- **A**: Digit 0
- **B**: Digit 1
- **C**: Upper and lower colons
- **D**: Digit 2
- **E**: Digit 3

Each digit consists of seven segments (A-G) that can extend or retract to form numbers or symbols. When a segment extends, LEDs behind it provide a uniform glow. The Light Dependent Resistor (LDR) above Digit 1 (on the back) senses ambient light and automatically adjusts the LED brightness for optimal visibility. LEDs turn off when the segment retracts to save power.

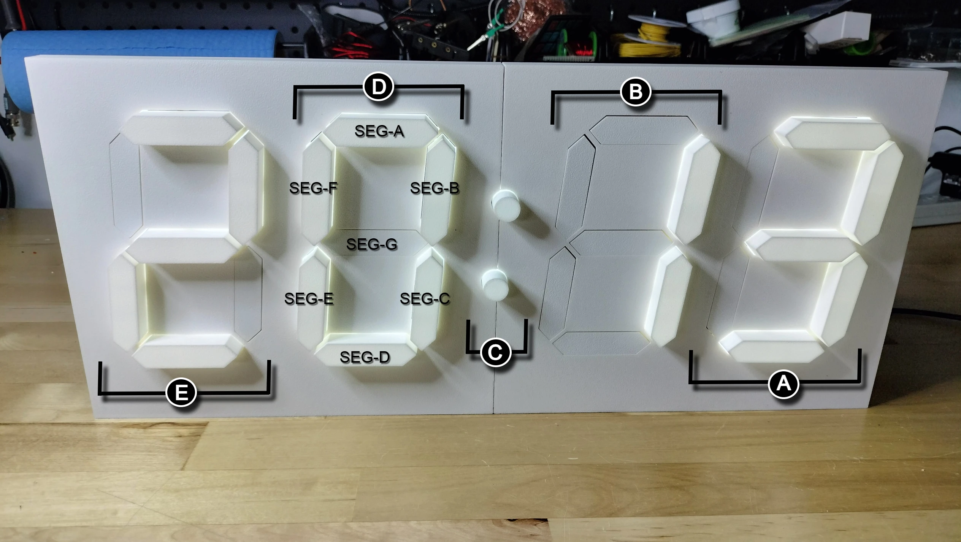
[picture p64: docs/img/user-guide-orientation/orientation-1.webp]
Front of Display


### Display Modes and Scheduler Actions

The Kinetic Display can be customized to show different information at scheduled times, see the user guide on [Schedule Creation and Management](schedule.md) for details. The scheduler determines which of the following modes is active:

1. **Local Time** (12 or 24 hour): Both colons extended. Shows the current time.
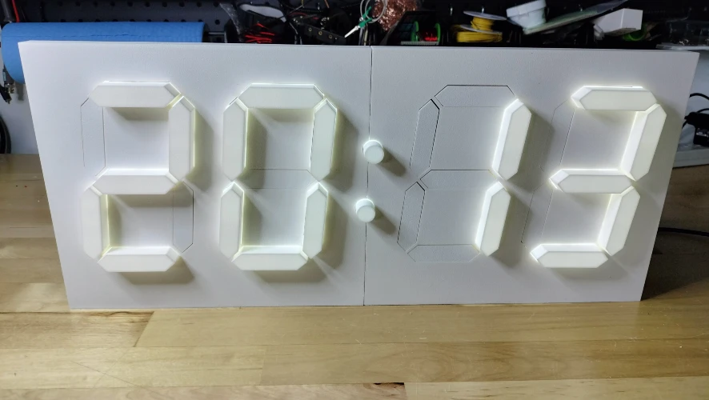
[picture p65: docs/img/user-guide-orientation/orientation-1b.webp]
Time Mode
    
2. **Date** (Month and Day): Both colons retracted. Shows the current date.
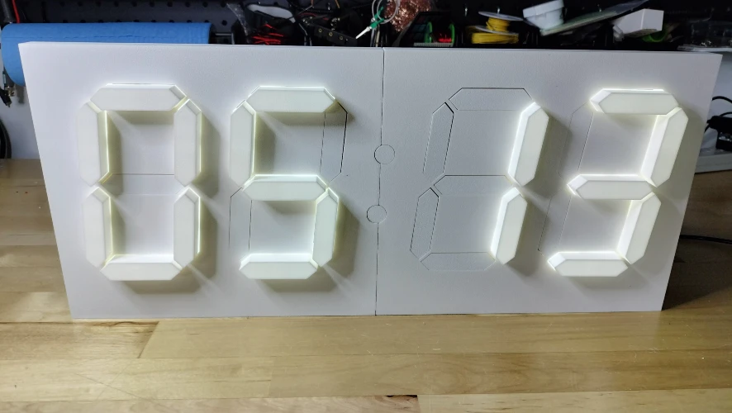
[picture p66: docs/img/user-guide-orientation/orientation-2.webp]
Date Mode
    
3. **Internal Temperature** (°C or °F): Upper colon extended, lower colon retracted. Shows the room temperature.
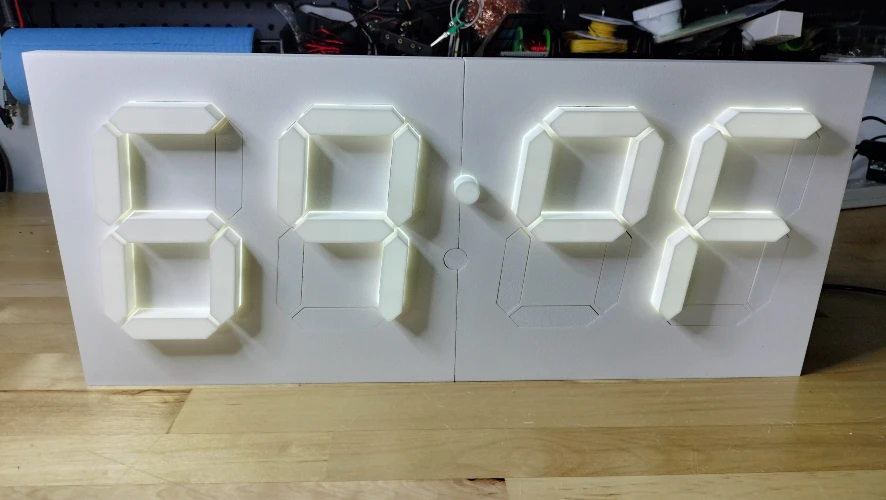
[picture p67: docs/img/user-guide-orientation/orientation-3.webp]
Internal Temp
    
4. **Internal Humidity** (%): Upper colon extended, lower colon retracted. Shows the room humidity.
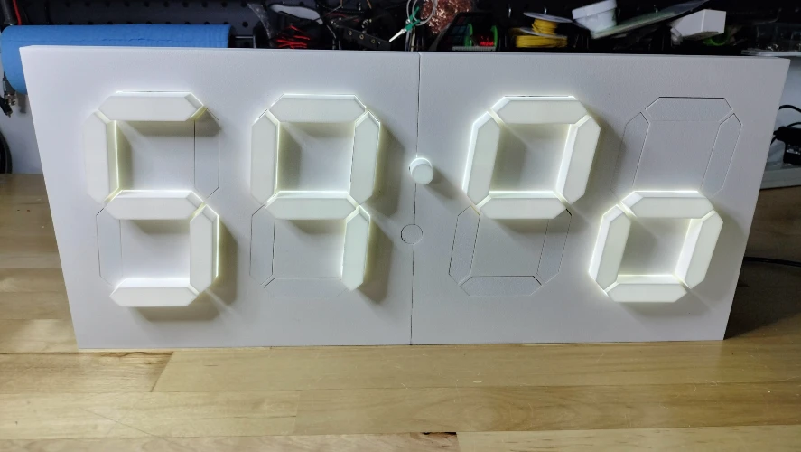
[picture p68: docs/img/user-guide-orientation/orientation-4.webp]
Internal Humidity
    
5. **External Temperature** (°C or °F): Lower colon extended, upper colon retracted. Shows the outdoor temperature.
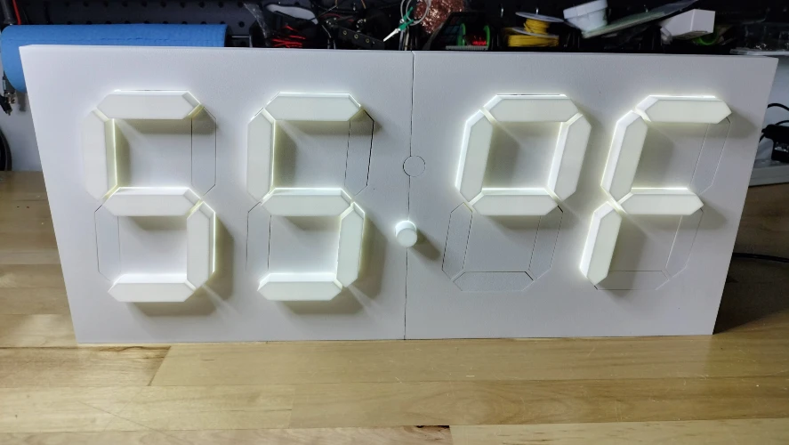
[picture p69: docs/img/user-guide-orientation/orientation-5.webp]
External Temp
    
6. **External Humidity** (%): Lower colon extended, upper colon retracted. Shows the outdoor humidity.
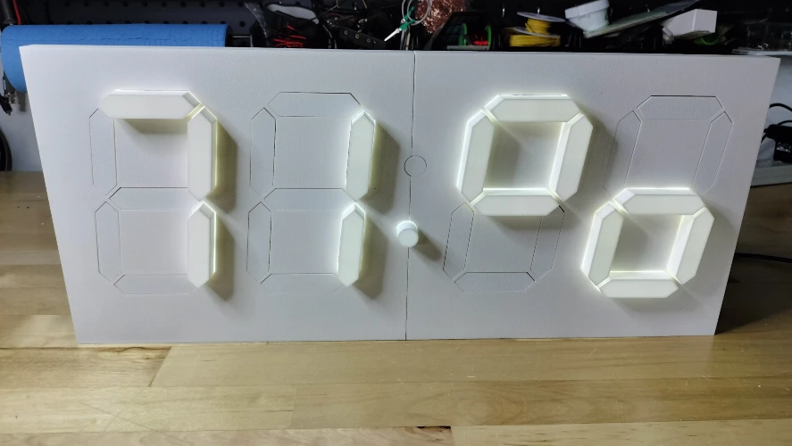
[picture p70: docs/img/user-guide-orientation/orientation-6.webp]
External Humidity
    
7. **Digit Type**: Choose between human or alien digit styles. See the [translation table for alien digits](../userguide/digittype.md). Example of the alien digit type:
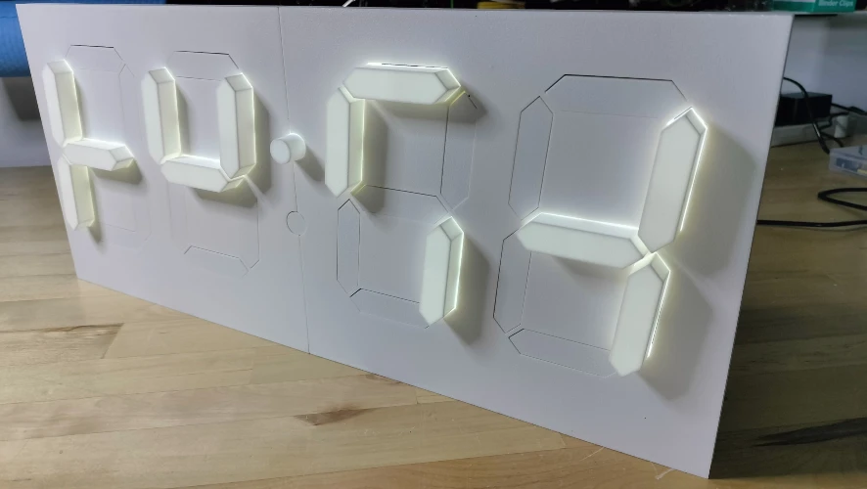
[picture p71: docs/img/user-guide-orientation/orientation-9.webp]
Alien Digits
    

---

## Top of Display

The top profile of the display is shown below with the short-form stand. For added stability or to protect the power management system from pets, you can install a long-form stand with a protective guard.

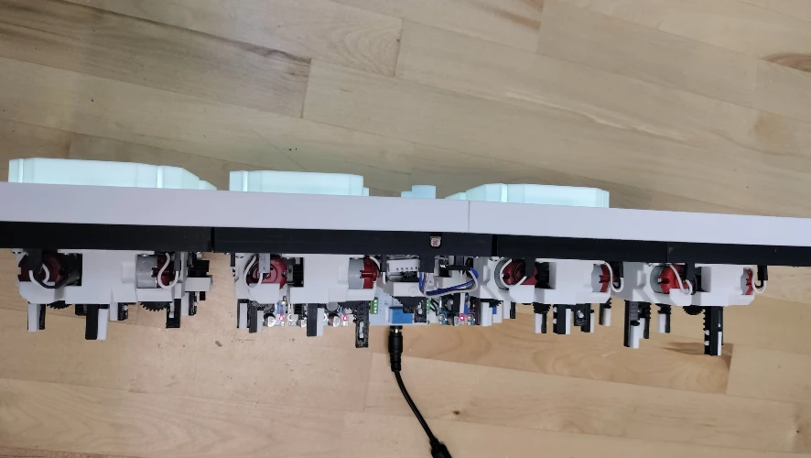
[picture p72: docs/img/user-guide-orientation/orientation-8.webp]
Top of Display


---

## Back of Display

Refer to the labeled picture below to identify the main components on the back of the display:

**A** = **Light Dependent Resistor (LDR):** Senses ambient light and adjusts LED brightness automatically.

**B** = **On/Off Switch:** Controls power and has different functions depending on its position. See the On/Off switch guide for details.

**C** = **Digital Humidity Temperature (DHT-22) Sensor:** Measures internal room temperature and humidity.

**D** = **Segment Actuator:** There are 30 actuators in total, including those for the colons, responsible for moving the segments.

**E** = **Digit Raspberry Pi Pico 2040 Microcontroller:** Four Picos (one per digit, labeled 0-3) act as CPUs for each digit, handling:

- Motor driver control for segment movement
- LED control for segment illumination
- Communication with the main conductor PCB via UART

**F** = **Conductor and Colon Raspberry Pi Pico 2040 W Microcontroller:** The Pico W (conductor) operates the colons and acts as the central command for the display, handling:

- Sending display and brightness commands to digits
- Broadcasting its own Wi-Fi service for wireless settings changes (Admin mode)
- Managing the scheduler for time, date, and weather display
- Setting local time and weather by connecting to Wi-Fi and external APIs
- Managing low-power mode by controlling power to digits 0-3

**G** = **Barrel Jack for 12V Power Supply:** The stand with the barrel jack also houses the power management system. The On/Off switch has different modes depending on the power connection. See the [On/Off switch user guide](spdtswitch.md) for more details.

!!! note
    Plug the 12V power supply into the barrel jack **before** plugging the power supply into the wall outlet.

Back of Display

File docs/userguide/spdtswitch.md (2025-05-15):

# User Guide – On/Off Switch

The Kinetic Display features a physical SPDT (Single Pole Double Throw) switch on the back of the unit. This switch lets you easily change between configuration mode and normal operation, and also helps save power.

Switch Position Diagram

---

## What Does the Switch Do?

The On/Off switch has two main functions:

1. **Operating Mode Selection**
2. **Power Management**

### 1. Operating Mode Selection

The switch determines how your display behaves depending on its position and when you plug in the power:

| Power State | Switch Position | Mode | What Happens |
|---|---|---|---|
| Plug in with switch **ON** | ON | Normal | Display runs your schedule, shows time, date, temp, etc. |
| Plug in with switch **OFF**| OFF | Configuration | Display creates a WiFi hotspot for settings changes |
| Already plugged in, set to **OFF** | OFF | Low Power | Digits turn off, controller stays on (saves power) |

### 2. Power Management

The switch controls a relay that turn off the digits when they're not needed, reducing energy use and wear.

---

## How Each Switch Position Works

### OFF Position

**When you set the switch to OFF and plug in the display:**

- The display creates a WiFi access point named `kinetic-display` (password: `12oclock`)
- You can connect to this network and visit [http://192.168.4.1](http://192.168.4.1) to change settings, WiFi, or schedules

**When you set the switch to OFF while the display is already running:**

- The display enters a low-power state
- All digit segments retract and turn off
- The controller stays on, but non-essential components are powered down

### ON Position

**When you set the switch to ON after saving settings:**

- The display connects to your home WiFi
- Time is synchronized automatically
- The display follows your selected schedule, showing time, date, temperature, and more
- All sensors and features are active (indoor/outdoor temp, humidity, light sensor, etc.)

---

## Scheduled Hibernation (Automatic Power Saving)

You can also schedule the display to hibernate automatically, even if the switch is ON. Just add an event with `event: 9` to your schedule. When this event triggers, the display will enter low-power mode for the specified time.

**Example schedule entry:**

```json
{
  "hour": 22,    // At 10:00 PM
  "minute": 0,
  "second": 0,
  "elapse": 480, // Hibernate for 480 minutes (8 hours)
  "event": 9     // Hibernate mode
}
```

---

## Why Use the On/Off Switch?

- **Save Energy:** Reduce power use when the display isn’t needed
- **Extend Component Life:** Less wear on moving parts
- **Easy Setup:** Quickly switch to configuration mode for WiFi or schedule changes
- **Flexible:** Use both manual (switch) and automatic (scheduled) hibernation

!!! tip "Power Saving"
    For best energy savings, use the OFF position when you don’t need the display for a while, or set up scheduled hibernation for overnight hours.

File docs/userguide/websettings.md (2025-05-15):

# User Guide - Web Service and Settings

The Kinetic Display features a built-in web service that allows you to easily configure and personalize your display using any device with Wi-Fi and a web browser. Having adjustable settings for your kinetic display offers several advantages:

- **Personalization:** Tailor the display's schedule, time format, temperature units, and digit style to match your preferences and environment.
- **Convenience:** Make changes from your phone or computer without needing to reprogram or physically access the device.
- **Adaptability:** Quickly update Wi-Fi credentials, time zones, or schedules if you move the display or your needs change.
- **Reliability:** Built-in test and recovery options help ensure the display operates correctly after power loss or network changes.
- **Energy Efficiency:** Schedule sleep and wake times to save power and extend the life of your display.

This guide will walk you through connecting to the display's Wi-Fi access point, accessing the web-based settings page, and understanding each available setting.

## 1. Start the Kinetic Display's Wifi Access Point

1. **Unplug** the display's 12V power supply.
2. Set the switch on the back of the display to the **Off** position.
3. **Plug in** the display's 12V power supply.

---

## 2. Connect Your Device to the **kinetic-display** Wifi Access Point (AP)

!!! note
    Complete the previous step to start the Kinetic Display's Wifi Access Point before proceeding.

### Connect from a Mobile Device

1. Open a QR code reader app on your mobile device.
2. Scan the QR code labeled **"SSID"** on the back of the display, or scan the image below:

    SSID

3. Tap **"kinetic-display"** in the list of Wifi access points.

    connectWifi

### Connect from a Computer

1. Open your computer's Wifi settings.
2. Select **"kinetic-display"** from the list of Wifi access points.
3. Enter the password: **12oclock**
4. Click **Connect**.

---

## 3. Access the Web Service Settings Page

!!! note
    You must be connected to the Kinetic Display's Wifi Access Point before continuing.

### Access from a Mobile Device

1. Open a QR code reader app on your phone.
2. Scan the QR code labeled **"URL"** on the back of the display, or scan the image below:

    connectWifi

3. Open the URL: [http://192.168.4.1](http://192.168.4.1)

    openURL

### Access from a Computer

1. Open a web browser.
2. Type `192.168.4.1` into the address bar and press **Enter** or **Return**.

---

## 4. Settings Overview

The screenshot below shows the Kinetic Display Control Settings page when opened for the first time.

setting-webpage

### Key Settings

1. **Schedule**
    - **Dropdown selection:** Choose from 5 prebuilt schedules, or add your own, see the user guide on [Schedule Creation and Management](schedule.md).
    - settings-1
    - **Add Schedule** and **Delete Schedule** to customize the list of schedules, see the user guide on [Schedule Creation and Management](schedule.md) for details.
2. **Wifi SSID and Wifi PWD**
    - Enter your home Wifi network name (SSID) and password (PWD).
    - The default values are `SSID` and `Password`. Change these to your actual Wifi credentials.
3. **Time**
    - Select **12** or **24** hour time display (default: 12 hour).
4. **TempCF**
    - Choose to display temperature in **Celsius** or **Fahrenheit** (default: Fahrenheit).
5. **TimeZone**
    - Select your time zone. By default, **By IP Address** is selected, which uses your external IP to determine local time. Selecting a named time zone will use that for time retrieval.
    - settings-2
6. **Display Motor Wait Time**
    - Set a value between **15** and **30** milliseconds (default: 16 ms). This controls how long the motor is on when a segment moves.
7. **Display Motor Speed**
    - Set a value between **50** and **99** percent (default: 85%). Higher values make segments move faster.
8. **Test on Startup**
    - Choose **Test** or **No Test**.
    - **Test:** Each digit and colon will extend and retract all segments on startup, then begin scheduled actions. Useful for ensuring all segments are working.
      settings-5
    - **No Test:** The display resumes from its last known state after power loss.
    - The state of the Kinetic Display is preserved even when the power is inadvertently turned off, such as a power outage. When the power is turned back after a power outage, the display will resume from its last known state when the setting is **No Test**. For example, the display is running normally and the power outage began at 10:30 and ended at 11:15, then all the digits except digit 3 would change on startup. If the setting is set to **Test**, then the display will run its animated segment test and clear all digits from 3 to 0 on the display before resuming.
9. **Digit Style or Type**
    - Choose **Human** or **Alien**. See the [Digit Type Table](./digittype.md) for details.
    settings-6

---

## 5. Save and Apply Settings

1. Click the **Save** button.
2. When prompted, click the **Shut Down** button. This will turn off the kinetic-display Wifi and web service, and switch the display to use your home Wifi credentials.

    settings-3

3. Set the switch on the back of the display to the **On** position.
4. Close the browser window when you see the following screen:

    settings-4

!!! note
    It can take up to a minute for the display to begin showing scheduled actions after saving settings.

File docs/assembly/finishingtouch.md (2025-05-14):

# Finishing Touch

## QR Code Installation

1. Print the following QR codes found from your forked repo at [../img/QRcodes/qrcode.png](../img/QRcodes/qrcode.png).

    qrcode

2. Separate and trim the QR codes. Using a piece of celophane tape to adhere each at the following location. Place the SSID QR code **(A)** on the  digit 3 backplate between segments D and C.  Place the URL QR code to the `admin.html` settings web page **(B)** on the digit 0 backplate also between segements D and C.

    qrcodelocation

3. Turn the **On/Off** switch to the **Off** position.
4. Plug the 12v power supply into the barrel jack then follow the user's guide to [configure the kinetic display settings](../userguide/websettings.md).

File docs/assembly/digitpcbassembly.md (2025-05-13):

# Digit PCB Assembly

The display has 4 digits, numbered from right to left (0-3) when viewed from the front. The digit PCBs are for digits 0, 2, and 3, while the controller PCB (digit 1) includes the colons. The digit PCBs are the foundation of the display and serve several important functions:

- **Mechanical Backstop**: Provides a sturdy backstop for the actuator's segment when retracting into the display.
- **Uniform Lighting**: Ensures consistent light dispersion for each segment, creating a uniform glow without hotspots.
- **Efficient Circuitry**: Reduces wiring complexity, connects components efficiently, and ensures reliable, cost-effective, and consistent quality.

This guide details the assembly of the digit PCBs. Below are images of the fully assembled PCBs covered in this section.

Front face fully assembled.
digit pcb front face

Back side fully assembled.
digit pcb back side

## Prerequisites

- [Fabrication of the digit PCBs](../createandorder/pcb.md)
- Table of components and tools

***Table of components***

| Quantity | Component | Image |
| :--: | :---| :-----: |
| 4 | 16 pin IC socket | component-1 |
| 4 | L293D stepper motor driver | component-2 |
| 2 | 20 pin female header connector | component-3 |
| 1 | 20 pin single row breakaway male connector | component-4 |
| 2 | 2 Pin PCB Mount Screw Terminal Block Connector Straight Pin | component-5 |
| 1 | 0.1μ farad ceramic capacitor | component-6 |
| 1 | 1μ farad electrolytic capacitor | component-7 |
| 28 | 5mm Flat top LED, anode long lead (any color) | component-8 |
| 1 | Raspberry Pi Pico 2040 with Headers | component-9 |
| 3 | Digit PCBs | See [labelling the digit PCBs](#label_the_digit_pcb) |

***Table of tools***

| Required | Tool | Image |
| :---: | :--- | :---: |
| Yes | Soldering station | tool-4 |
| Yes | 0.8mm 1.76oz RoHS flux core solder | tool-1 |
| Yes | Mini flush cutters | tool-6 |
| Yes | Isopropyl Alcohol | tool-3 |
| Yes | Cotton Facial Pads | tool-2 |
| No  | Label maker | tool-5s |

## Label the Digit PCB

1. **Label the Front Side**: Using a label maker or tape and pen, create labels for "0", "2", and "3". Attach the labels to the **front-facing side** of each digit PCB as shown below. Note that digit 0 **(C)** in the image is a completed PCB ready for mounting.
   digitpcb-2
1. **Label the Back Side**: Attach the same labels to the **back-facing side** of each digit PCB as shown below.
   digitpcb-3

## Add the 16 Pin Headers

1. **Insert the Header**: From the front side of the PCB, align the notch on the 16-pin header with the silk screen outline. Insert the header into the through holes.
   digitpcb-4
1. **Solder the Pins**: Turn the PCB over and solder all 16 pins. Repeat for all 4 headers.
   digitpcb-5
1. **Trim and Smooth**: From the back, snip the soldered pins flush, then touch up with solder to create smooth rounded beads.
   digitpcb-6
1. **Clean the Flux**: Use a cotton pad dabbed with isopropyl alcohol to remove flux residue.
   digitpcb-8

## Add the 28 LEDs

!!! note
    Test your LEDs on a breadboard before soldering to ensure consistent color and brightness. Use a digital camera to detect variations.

1. **Insert LEDs**: Start with segment "A". Insert the LED's **long lead (anode)** into the "+" through hole. Repeat for all LEDs in segment "A".
   digitpcbLEDs-1
1. **Solder and Trim**: Turn the PCB over, solder the LED pins, and snip off the excess. Smooth the clipped pins with solder.
   digitpcbLEDs-3
1. **Clean the Flux**: Remove flux residue with a cotton pad and isopropyl alcohol.
   digitpcbLEDs-4
1. **Repeat for All Segments**: Complete the process for segments B through G. The image below shows all LEDs soldered in place.
   digitpcbLEDs-5

## Add the Motor Pins

1. **Break Out Pins**: Use needle nose pliers to break out 7 pairs of 2.54mm male breakaway pins.
   digitpcbmotorpins-2
1. **Insert Pins**: Place the short end of each pin pair into the actuator segment through holes (seg-A to seg-G) on the back of the PCB.
   digitpcbmotorpins-3
1. **Solder and Trim**: Solder the pins on the front side, snip them flush, and smooth with solder.
   digitpcbmotorpins-5
1. **Clean the Flux**: Remove flux residue with isopropyl alcohol.
   digitpcbmotorpins-6

## Mount the Motor Drivers

1. **Align the Driver**: Orient the motor driver so the notch aligns with the 16-pin header.
   digitpcbmotordriver1
1. **Insert Carefully**: Insert the motor driver into the header, ensuring no pins are bent.
   digitpcbmotordriver2
1. Repeat the install for the remaining motor drivers.

## Add the PCB Mount, Two pin (2P) Terminal Block Connectors

1. On the front of the digit PCB, insert the PCB two pin terminal block connector into the 5v through holes so the face of the connector (where the wires are inserted) points toward the LEDs on the PCB.
digitpcbconnector-1
2. Solder the terminal block connector pins on the back of the digit PCB.
digitpcbconnector-2
3. On the front of the digit PCB position the 2 pin terminal block connector facing away from the LEDs. For **PCBs labelled "2" & "3"**, insert the connector pins into the `UART Tx-1/Rx-1` through holes. For the digit **PCB labelled "0"**, insert the connector into the `Tx-0/Rx-0` through holes.
digitpcbconnector-3
4. On the back of the digit PCB, solder the remaining connector pins, cut the pins flush, resolder to a smooth bead, then remove the flux wth a cotton dabbed with isopropyl alcohol.
digitpcbconnector-4

## Add the Electrolytic and Ceramic Capacitors

1. On the front of the digit PCB, align the electrolytic capacitor `-` sign opposite the `+` printed on the PCB for capacitor `c1`, see the picture below. Insert the pins into the through holes, then turn the digit PCB over to the back side and solder the capacitor.
digitpcbcapacitor-1
2. On the front of the digit PCB, insert the ceramic capacitor pins into the through holes titled `c2`. Turn the digit PCB over to the back and solder the capacitor.
!!! note
    Ceramic capacitors do not have polarity and can be inserted in any direction.
digitpcbcapacitor-2
3. On the back of the digit PCB, cut the pins flush, resolder to a smooth bead, then remove the flux with a cotton dabbed with isopropyl alcohol.
digitpcbcapacitor-3

## Add the 20 pin Headers and Install the Microcontroller

1. On the back side of the PCB, place the two 20 pin headers into the through holes for `RASP1`. Carefully turn over the PCB while keeping the 20 pin headers in the through holes.
digitpcbmicrocontroller-1
1. Level the PCB and adjust the two 20 pin headers so they are perpendicular to the PCB. Solder the pins once in place. Snip all 40 of the pins flush, resolder each to a smooth bead, then remove the flux with a cotton dabbed with isopropyl alcohol.
digitpcbmicrocontroller-2
1. Orient the Raspberry Pi Pico 2040 microcontroller so the USB port is facing in the same direction as the PCB silk screen, then gently mount the microcontroller onto the header.
digitpcbmicrocontroller-3

Congratulations for assembling a digit PCB! Be sure to test the digit PCB before assembling the next one.

## Digit Schematics

The schematic diagrams in this section represent the **Digit Motor Controller** and **Digits Microcontroller** circuits:

- *Motor Controller Circuit* drives the actuator motors for each segment (A-G) to physically move the segments into position, turns on the segment LEDs when extended, and turns off the segment LEDs when retracted.
- *Microcontroller Circuit* controls the LEDs for segment illumination (brightness) and communicates with the main controller (Raspberry Pi Pico W 2040) to receive display commands.
  
Together, these circuits enable the digit PCBs to display numbers and characters as part of the larger kinetic display system. Below is an explanation of the components, their purpose, and how the circuitry functions.

### **Digit Motor Controller Schematic**

The schematic in the section shows the motor control circuitry for the digit's seven-segment actuators (A-G). Each segment is controlled by a motor driver IC (L293D) connected to the Raspberry Pi Pico 2040. Note the L293D IC motor driver is considered outdated, but used in this circuit as it works well with toy motors and costs slightly less. For more details see the [L293D motorcontroller datasheet](https://www.digikey.com/htmldatasheets/production/237694/0/0/1/l293dd.html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).

#### **Key Motor Controller Components and Their Purpose**

1. **L293D Motor Driver ICs (U1, U2, U3, U4)**:</br>
    *Purpose*: Control the bidirectional movement of the actuator motors for each segment (A-G).</br>
    *Functionality*: Each IC controls two segments, allowing precise movement of the actuators.</br>
    *Pins*:
     - `ENABLE1` and `ENABLE2`: Controls the motor speed.
     - `INPUT1`, `INPUT2`, `INPUT3`, `INPUT4`: Control the CW (Clockwise) and CCW (Counter clockwise) direction of the motor.
     - `OUTPUT1`, `OUTPUT2`, `OUTPUT3`, `OUTPUT4`: Provide the output signals to the motors.
2. **Actuator Motors (SEG-A to SEG-G)**:</br>
    *Purpose*: Physically extends and retracts the segments of the seven-segment display to create the desired digit.</br>
    *Pins*:
     - `CW` extends the segment and `CCW` retracts the segment: Control the extension and retraction of the actuator.
3. **Capacitors (C1, C2)**:</br>
    *Purpose*: Provide power decoupling and noise filtering for the motor drivers.</br>
    `C1` (1μF): Stabilizes the power supply for the motor drivers.</br>
    `C2` (0.1μF): Filters high-frequency noise.
4. **GPIO Pins (from Raspberry Pi Pico 2040)**:</br>
    *Purpose*: Send control signals to the motor drivers.</br>
    *Pins*:
     - `GPIO11`, `GPIO12`, `GPIO15`, etc.: Control the `INPUT` and `ENABLE` pins of the motor drivers.

#### **How the Motor Controller Circuit Works**

1. **Motor Control**:</br>
      - The Raspberry Pi Pico 2040 sends signals to the `INPUT` and `ENABLE` pins of the L293D ICs.</br>
      - Based on these signals, the motor driver controls the direction and speed of the actuator motors.
2. **Segment Movement**:</br>
      - Each segment (A-G) is connected to a motor. The motor moves the segment into position to display the desired digit.
3. **Power Stabilization**:</br>
      - The capacitors `C1` and `C2` ensure stable operation of the motor drivers by filtering noise and stabilizing the power supply.

digitschematic-1

### **Digit Microcontroller Schematic**

The schematic in this section shows the microcontroller circuitry for controlling the LEDs and communicating with the motor controllers.

#### **Key Microcontroller Components and Their Purpose**

1. **Raspberry Pi Pico 2040 (Microcontroller)**:</br>
    *Purpose*: Acts as the central processing unit for the digit PCB.</br>
    *Functions*:
      - Sends control signals to the motor drivers for segment movement.
      - Controls the LEDs for segment illumination.
      - Communicates with the main controller PCB via UART.
1. **LEDs (A-LED1 to G-LED4)**:</br>
    *Purpose*: Illuminates the segments of the seven-segment display.</br>
    *Configuration*:
     - Each segment (A-G) has four LEDs connected in parallel.
     - The anode `+` is connected to the GPIO pins, and the cathode `-` is connected to ground.
     - Brightness is controlled by the GPIO PWM signals from the microcontroller.
1. **Resistors (not used in lieu of PWM)**:</br>
    *Purpose*: Prevents the LEDs from exceeding their maximum rated power capabilities. The software prevents any LED PWM signal from exceeding a 220 ohm resistor for 3.3v and therefore resistors are not needed.
1. **UART Connector**:</br>
    *Purpose*: Provides communication between the digit PCB and the main controller PCB.</br>
    *Pins*:
     - `Rx-1`, `Tx-1`, `Rx-0`, `Tx-0`: Used for transmitting and receiving data.
1. **Capacitors (C1, C2)**:</br>
    *Purpose*: Provide power decoupling and noise filtering for the microcontroller and LEDs.</br>
    `C1` (1μF): Stabilizes the power supply for the LEDs.</br>
    `C2` (0.1μF): Filters high-frequency noise.

#### **How the Microcontroller Circuit Works**

1. **Segment Control**:
      - The Raspberry Pi Pico 2040 controls motor direction, extending or retracting the segment, and speed from GPIO pins connected to the motor controllers.
      - The microcontroller determines the length of time the motor is running (between 1/5th and 1/4th of a second), the CW (extend) or CCW (retract) direction of the actuator, and the speed of the motor which is a value typically between 50% to 100% of 5v.
2. **LED Control**:
      - The Raspberry Pi Pico 2040 controls the LEDs by PWM from the GPIO pins that are connected to the anode of each LED.
      - This allows the microcontroller to turn on/off specific LEDs, control the brightness, and illuminates the desired segments.
3. **Communication**:
      - The UART connector allows the digit PCB to receive UART commands from the controller and digit 1 PCB.
      - UART commands include which digit to display and brightness levels, as well as various actuator and digit settings.
4. **State**:
      - The Raspberry Pi Pico 2040 stores the digit state at all times in order to gracefully transition from one number or character to the next and handle graceful or ungraceful power off situations.
      - The state includes which segment is extended or retracted, the type of character map used by the digits, as well as the speed and length of time to run the motors.
5. **PowerCommands Stabilization**:
      - The capacitors `C1`, `C2` ensure stable operation of the LEDs and microcontroller by filtering noise and stabilizing the power supply.

digitschematic-2

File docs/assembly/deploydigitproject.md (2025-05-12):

# Deploy the Digit Project to the Digit PCB

In this guide you will upload code from the **digit** folder on your computer to your Raspberry Pi Pico 2040.

## Prerequisites

- Completed the assembly and soldering of the [Digit PCB](digitpcbassembly.md)
- Created a fork of the Kinetic-Display GitHub repository (see [Software and Microcontroller Preparation](../prerequisitesoftware.md))
- Deployed the `digit` directory (see [Software and Microcontroller Preparation](../prerequisitesoftware.md))

## Configure and Deploy the Digit Project

1. **Connect the Digit PCB**: Connect your computer to the digit PCB's Raspberry Pi Pico as described in [Verify Micropython on your Raspberry Pi Pico](../prerequisitesoftware.md).
1. **Open the Deploy Folder**:  
      - In VS Code, select **(A)** **File -> Open Folder...**.  
      - **(B)** Navigate to the **deploy/digit** folder you deployed during step 4 in [Fork and Clone the Repository](../prerequisitesoftware.md).  
      - **(C)** Click the "Select Folder" button.  
      
1. **Update the digit.json File**:  
      - In the Explorer pane, click the **Explorer icon** (**A**) in the left [Activity bar](https://code.visualstudio.com/docs/getstarted/userinterface#_basic-layout).  
      - Open the `digit.json` file (**B**) and change the **"digit":** value (**C**) to match the PCB's labeled number (0-3).  
      - Save the file after making changes.  
    !!! warning
        Ensure the digit value in the `digit.json` file matches the PCB's labeled value to avoid incorrect behavior.
    testdigitpcb-2
1. **Create a New Terminal**:  
      - **(A)** Click the ellipsis (`...`) in the terminal pane.  
      - **(B)** Select **Terminal -> New Terminal** from the submenu.  
   testdigitpcb-3
1. **Select the MicroPico vREPL**:  
      - Connect your computer's USB port to the digit PCB's Raspberry Pi Pico.  
      - In the terminal pane, **(A)** select the drop-down menu and **(B)** click the **MicroPico vREPL** submenu item.  
   testdigitpcb-4
1. **Upload the Project**:  
      - Click **All Commands** (**A**) on the [status bar](https://code.visualstudio.com/api/ux-guidelines/status-bar).  
      - In the Command text field (**B**), type "**Upload**" after "**> MicroPico:**".  
      - Select the dropdown option **MicroPico: Upload project to Pico**.  
   testdigitpcb-5

Congratulations on successfully uploading the code to the digit PCB's Raspberry Pi Pico!

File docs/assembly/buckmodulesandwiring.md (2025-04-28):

# Buck Module Wiring

Buck converters are essential for converting 12V DC to 5V DC because they efficiently step down the voltage while minimizing energy loss. Unlike linear regulators, which dissipate excess voltage as heat, buck converters use high-frequency switching and inductors to transfer energy more efficiently. This makes them ideal for powering sensitive electronics like micro controllers and LEDs, as they provide stable output voltage, reduce heat generation, and improve overall system reliability.

This guide provides detailed instructions for assembling and wiring DC to DC variable buck converter modules in a Kinetic Display system. It includes a list of required components and tools, step-by-step guidance for wiring and securing the modules, and calibration instructions to ensure proper voltage output.

1. **Correct Wiring**: Proper routing and connection of wires are critical to ensure the display functions correctly. Incorrect wire lengths or connections can lead to assembly issues or electrical faults.
1. **Voltage Calibration**: The buck converters step down the input voltage from 12V to a stable 5.0-5.1V output. Calibration ensures the modules provide the correct voltage to prevent damage to connected components or malfunctions.
1. **Safety Measures**: Follow anti-static precautions and use proper tools to avoid damaging sensitive electronics during assembly.

This guide is essential for ensuring the reliability and safety of the Kinetic Display system.

## Prerequisites

- 3D print the Conductor and Digits TPU gaskets.
- 3D print the Display stand.

***Table of components***

| Quantity | Component | Image |
| :--: | :--- | :-----: |
| 5 | DC to DC variable buck converter module | component-31 |
| 1 | 12V 5A Power Supply, AC DC Converter 100-220V to 12 Volt 5 Amp Transformer 5.5x2.1mm Plug | component-33 |
| 10M | White 28 AWG Gauge Flexible Silicone Rubber Electric Wire | component-28 |
| 10M | Black 28 AWG Gauge Flexible Silicone Rubber Electric Wire | component-29 |
| 50cm | (optional) 28 AWG Gauge heat shrink | component-30 |
| 10 | M1.7x6mm Cross Round Head with Washer Self Tapping Screw 304 Stainless Steel Screws | component-32 |

***Table of tools***

| Required | Tool | Image |
| :---: | :--- | :---: |
| Yes | Multimeter | tool-16 |
| Yes | Soldering station | tool-4 |
| Yes | 0.8mm 1.76oz RoHS flux core solder | tool-1 |
| Yes | Mini flush cutters | tool-6 |
| Yes | Wire stripper | tool-9 |
| No | Label maker | tool-5 |

## PCB and Stand Layout

This section ensures wiring for the PCBs is oriented for the mounting of the buck modules and wiring.

1. Remove the Raspberry Pi Pico and Pico W 2040 from the PCBs. These will be added later when it is safe to do so.
2. Lay the PCBs face up with Digit 0 on the far right and Digit 3 on the far left. Position the stand below the PCBs so the barrel jack is between the Conductor and Digit 1 PCB and Digit 2 PCB.  
   buckmodulesandwiring-1
3. Place the TPU gaskets on the PCBs. Note that the wiring lays over the gaskets.  
   buckmodulesandwiring-2

## Wiring the Buck Modules

This section details wiring the buck converter modules to the PCBs. Be sure to follow the instructions to get the wire lengths correct. Incorrect lengths may result in wires being too short or too long, preventing the display face from fitting correctly. Each buck module has an `In +` and `In -` on one side for the 12V input, and an `Out +` and `Out -` on the opposite side for the converted 5V output. This section also covers how to calibrate the variable buck module to provide 5.0V to 5.1V output.

The picture below is the wiring diagram for the buck converter modules:  
buckmodulesandwiring-wiring

The picture below shows the completed wiring of the buck converter modules. The order of installation is **1, 2, 3** on the right, followed by **4** and **5** on the left:  
buckmodulesandwiring

!!! warning
    Use anti-static mats, an ESD wristband, and a grounding wire for the remainder of the Kinetic Display electronics assembly.

### Digits and Conductor

1. Following the picture below, place a buck converter module for Digit 0 on the rightmost support on the display stand. Strip 3mm of insulation from the black and white 28 AWG wire while on the roll starting then tin the stripped end with solder. **(A)** Route the two wires from the 5V terminal block connector on the Digit 0 PCB. **(B)** Slide two 3cm sections of heat shrink on the two wires but DO NOT APPLY HEAT, then **(C)** continue routing the wire around the relay, under the power management PCB and through the port on the PCB stand. **(D)** Finish unwinding the wire when you reach the end of the buck module as shown in the picture. Now that the length of wire is known from its route, snip off the wires next to the terminal block connector. **(A)** Strip 3mm of insulation then tin the stripped end with solder. Connect the white wire to the `+` on the `5V` terminal block connector and the black wire onto the `-`.  
   buckmodulesandwiring-3
1. Following the picture below, turn the Digit 0 buck module over to its backside and solder the white wire onto the `Out +` pad and the black wire onto the `Out -` pad.  
   buckmodulesandwiring-4
1. Following the picture below, turn the Digit 0 buck module 180 degrees while having its backside facing up. Strip 3mm of insulation from the black and white 28 AWG wire while on the roll starting then tin the stripped end with solder. Solder the white wire onto the buck module's `In +` pad and the black wire onto the `In -` pad.  
   buckmodulesandwiring-5
1. Turn the Digit 0 buck module over and secure it with M1.7x6mm self tapping screws onto the rightmost module supports on the display stand.  
   buckmodulesandwiring-6
1. Route the Digit 0 white and black wire to the power management PCB `C-12V-1` terminal block connector, provide about 10mm extra length in the wire before cutting them. Strip 3mm of insulation then tin the stripped end with solder. Connect the white wire to the `+` on the `C-12V-1` and the black wire onto the `-`.  
   buckmodulesandwiring-7
1. Following the picture below, place a buck converter module for Digit 1 to the left of the Digit 0 module. Strip 3mm of insulation from the black and white 28 AWG wire while on the roll starting then tin the stripped end with solder. Starting with the Digit 1 PCB, **(A)** Route the two wires from the 5V terminal block connector. **(B)** Slide one 3cm section of heat shrink on the two wires but DO NOT APPLY HEAT, then **(C)** continue routing the wire around the relay, under the power management PCB and through the port on the PCB stand. **(D)** Finish unwinding the wire when you reach the end of the second buck module as shown in the picture. Now that the length of wire is known from its route, snip off the wires next to the terminal block connector **(A)**. Strip 3mm of insulation then tin the stripped end with solder. Connect the white wire to the `+` on the `5V` terminal block connector and the black wire onto the `-`.  
   buckmodulesandwiring-8
1. Following the picture below, turn the Digit 1 buck module over to its backside and solder the white wire onto the `Out +` pad and the black wire onto the `Out -` pad.  
   buckmodulesandwiring-9
1. Follow the previous steps 3-5 for the Digit 1 buck module then connect the 12V black and white wire into the next available block terminals on `C-12V-1`. See the picture below for the assembled Digit 1 buck module.  
   buckmodulesandwiring-10
1. Place a buck converter module for the Conductor and Digit 1 to the left of the Digit 1 module. Strip 3mm of insulation from the black and white 28 AWG wire while on the roll starting then tin the stripped end with solder. On the backside of the Conductor and Digit 1 buck module, **(A)** solder the white wire onto the `Out +` pad and the black wire onto the `Out -` pad. Route the wire around the power management relay and **(B)** to the 5V terminal block connector.  
   buckmodulesandwiring-11
1. Clip the white and black wires, strip 3mm of insulation then tin the stripped end with solder. Connect the white wire to the `+` on the 5V terminal block connector and the black wire onto the `-`.  
   buckmodulesandwiring-12

## Calibrate the Buck Module Voltage, Part 1

buckmodulesandwiring-13

Follow using the picture above and start with the Digit 0 buck module furthest right. **(A)** Disconnect the black and white wire from the 5V terminal block and connect the probes from the multimeter set to measure DC voltage. **(B)** Plug the 12V power supply into the power management PCB barrel jack. **(C)** Turn the screw on the top of the potentiometer on the Digit 0 buck module counterclockwise until **(D)** the voltage measures between 5.0 and 5.1 volts. Note you'll have to turn the screw on the top of the potentiometer several times counterclockwise before the voltage begins to drop.

Repeat the steps above to calibrate Digit 1 and the Conductor buck modules to 5V.

## Wire Remaining Buck Modules

1. Following the picture below, place a buck converter module for Digit 3 to the far left mounting location. Strip 3mm of insulation from the black and white 28 AWG wire while on the roll starting then tin the stripped end with solder. **(A)** Unroll the two wires starting at the 5V terminal block connector on Digit 3 PCB. **(B)** Slide one 3cm section of heat shrink on the two wires but DO NOT APPLY HEAT, then **(C)** route the wire around the relay, under the power management PCB, and through the port on the PCB stand. **(D)** Finish unwinding the wire when you reach the end of the buck module as shown in the picture. Strip 3mm of insulation then solder the white wire to the buck module `Out +` pad and the black wire to the `Out -` pad. Now that the length of wire is known from its route, snip off the wires next to the terminal block connector **(A)**. Strip 3mm of insulation then tin the stripped end with solder. Connect the white wire to the `+` on the `5V` terminal block connector and the black wire onto the `-`.  
   buckmodulesandwiring-14
1. Following the diagram below, **(A)** solder the white wire onto the buck module's `In +` pad and the black wire onto the `In -` pad. Secure the module with two M1.7x6mm self tapping screws. **(B)** Route the Digit 0 white and black wire to the power management PCB `C-12V-1` terminal block connector, provide about 10mm extra length in the wire before cutting them. Strip 3mm of insulation then tin the stripped end with solder. Connect the white wire to the `+` on the `C-12V-1` and the black wire onto the `-`.  
   buckmodulesandwiring-15
1. Following the picture below, place a buck converter module for Digit 2 to the right of Digit 3. Strip 3mm of insulation from the black and white 28 AWG wire while on the roll starting then tin the stripped end with solder. Starting with the Digit 2 PCB, **(A)** unroll the two wires starting at the 5V terminal block connector. **(B)** route the wire around the relay, under the power management PCB, and through the port on the PCB stand. **(C)** Finish unwinding the wire when you reach the end of the buck module as shown in the picture. Strip 3mm of insulation then solder the white wire to the buck module `Out +` pad and the black wire to the `Out -` pad. Now that the length of wire is known from its route, snip off the wires next to the terminal block connector **(A)**. Strip 3mm of insulation then tin the stripped end with solder. Connect the white wire to the `+` on the `5V` terminal block connector and the black wire onto the `-`.  
   buckmodulesandwiring-16
1. Following the diagram below, **(A)** solder the white wire onto the buck module's `In +` pad and the black wire onto the `In -` pad. Secure the module with two M1.7x6mm self tapping screws. **(B)** Route the Digit 0 white and black wire to the power management PCB `C-12V-1` terminal block connector, provide about 10mm extra length in the wire before cutting them. Strip 3mm of insulation then tin the stripped end with solder. Connect the white wire to the `+` on the `C-12V-1` and the black wire onto the `-`.  
   buckmodulesandwiring-17
1. Position the heat shrink as per the picture of the completed wiring of the buck converter modules at the beginning of this document. Apply heat from your heat gun to complete the assembly of all the heat shrink.

## Calibrate the Buck Module Voltage, Part 2

Following the picture below with the Digit 3 buck module, **(A)** disconnect the black and white wire from the 5V terminal block, and connect the probes from the multimeter set to measure DC voltage. **(B)** Plug the 12V power supply into the power management PCB barrel jack. **(C)** Turn the screw on the top of the potentiometer on the Digit 3 buck module counterclockwise until **(D)** the voltage measures between 5.0 and 5.1 volts. Note you'll have to turn the screw on the top of the potentiometer several times counterclockwise before the voltage begins to drop.

Repeat the steps above to calibrate Digit 2 buck module to 5V.  
buckmodulesandwiring-18

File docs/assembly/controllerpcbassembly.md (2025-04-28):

# Conductor and Digit 1 PCB Assembly

Digit 1 and the colons are on a single PCB. Digit 1, powered by a Raspberry Pi Pico 2040, is identical to digits 0, 2, and 3 except it is contained on a single PCB with the conductor. The Raspberry Pi Pico W 2040 (conductor) operates the colons and serves as the central command and control for the display, performing the following functions:

- Sends commands to digits as to what to display (e.g., 0-9, A-F).
- Sends commands for the brightness of the digits.
- When in Admin mode, transmits its own Wi-Fi service to wirelessly change the display settings from a cell phone or computer.
- Manages the scheduler, which is the mechanism for displaying time, date, external temperature and humidity, and interior temperature and humidity.
- When connected to a Wi-Fi network, obtains its public-facing IP address, looks up the time zone it is located in, and sets the display to the local time.
- When connected to a Wi-Fi network, obtains the closest weather station and, depending on the scheduler, may display the external temperature and humidity.
- Manages the low power consumption mode by turning off the power to digits 0-3. When awakened, it turns on the power to digits 0-3.

Front face of the **Conductor and Digit 1** PCB fully assembled:  
front-face-controller-pcb  
Back side of the **Conductor and Digit 1** PCB fully assembled:  
back-face-controller-pcb

## Prerequisites

- [Fabrication of the conductor and digit one PCB](../createandorder/pcb.md).
- 3D print of the upper and lower colons.

***Table of components***

| Quantity | Component | Image |
| :--: | :--- | :-----: |
| 5 | 16 pin IC socket | component-1 |
| 5 | L293D stepper motor driver | component-2 |
| 4 | 20 pin female header connector | component-3 |
| 1 | 20 pin single row breakaway male connector | component-4 |
| 1 | Vertical Slide Switch Micro High Knob 3 Pin 2 Position 1P2T SPDT Panel Mount | component-18 |
| 6 | 2 Pin PCB Mount Screw Terminal Block Connector Straight Pin | component-5 |
| 2 | 0.1μ farad ceramic capacitor | component-6 |
| 2 | 1μ farad electrolytic capacitor | component-7 |
| 1 | 5mm 0.5 Ω ohm Photoresistor Resistor 5516 GL5516 | component-19 |
| 1 | S8550 TO-92 TH PNP Transistor | component-20 |
| 1 | 2N2222 TO-92 TH NPN Transistor | component-21 |
| 2 | 10K ohm 0805 Resistor 1/4w Metal Film Fixed Resistor | component-22 |
| 28 | 5mm Flat top LED, anode long lead (your choice of color) | component-8 |
| 2 | 3mm Flat top LED, anode long lead (your choice of color) | component-17 |
| 1 | Raspberry Pi Pico 2040 with Headers | component-9 |
| 1 | Raspberry Pi Pico W 2040 with Headers | component-16 |
| 1 | Conductor and Digit 1 PCB | See next section |

***Table of tools***

| Required | Tool | Image |
| :---: | :--- | :---: |
| Yes | Soldering station | tool-4 |
| Yes | 0.8mm 1.76oz RoHS flux core solder | tool-1 |
| Yes | Mini flush cutters | tool-6 |
| Yes | Isopropyl Alcohol | tool-3 |
| Yes | Cotton Facial Pads | tool-2 |

## Assemble Digit One

This section will guide you through following the relevant instructions from the **Digit 0, 2, & 3** PCB assembly to assemble **Digit 1** on the **Conductor and Digit 1** PCB.

1. On the front face of the **Conductor and Digit 1** PCB, [add the 16 pin headers](digitpcbassembly.md#add_the_16_pin_headers) as previously completed for the digit PCBs. Note the highlighted sections in the picture below where you'll add an additional 16 pin header to the **Conductor and Digit 1** PCB. Don't forget to snip all the pins flush on the back side of the **Conductor and Digit 1** PCB, resolder each snipped pin to a smooth bead, then remove the flux with cotton dabbed with isopropyl alcohol.  
1-controllerpcb
1. On the front face of the **Conductor and Digit 1** PCB, [add the 28 5mm LEDs](digitpcbassembly.md#add_the_28_leds) as previously completed for the digit PCBs. Be sure to insert the LED anode (long pin) into the through hole marked with a `+`. Do not solder the 5mm LED into the `Top-LED1` or `LWR-LED1` location on the **Conductor and Digit 1** PCB. Instructions later in this tutorial will detail how to install the 3mm LEDs into the `Top-LED1` and `LWR-LED1` locations. Finish soldering the 28 5mm LEDs by snipping all the pins flush on the back side of the **Conductor and Digit 1** PCB, resolder each snipped pin into a smooth bead, then remove the flux with cotton dabbed with isopropyl alcohol.  
2-controllerpcb
1. On the back of the **Conductor and Digit 1** PCB, [add the motor pins](digitpcbassembly.md#add_the_motor_pins). Note the highlighted sections in the picture below where there are two additional motor pins (pairs) you'll need to add for the colons, and an additional 3-pin connector for the Digital Humidity and Temperature (DHT) sensor. Don't forget to snip all the pins flush on the back side of the **Conductor and Digit 1** PCB, resolder each snipped pin to a smooth bead, then remove the flux with cotton dabbed with isopropyl alcohol.  
3-controllerpcb

## Colon Segments LEDs

In addition to the soldering equipment you needed when previously mounting the 5mm flat top LEDs, you'll need the two 3D printed colon segments, labeled **(A)** in the picture below, as fabricated in the [3D print the display parts](../createandorder/3dprints.md) document.

6-controllerpcb

1. Following label **(B)** in the picture above, insert the **3mm** flat top LEDs into `Top-LED1` and `LWR-LED1` on the front face of the **Conductor and Digit 1** PCB. Follow the same 5mm LED install process and be sure to insert the long lead anode of the LED into the `+` through hole.
1. Following the picture below, slide the colon segments over the 3mm LED. Note the lower base of the LED lense may need to be lightly sanded with 300 grid sandpaper if it does not easily slide into the colon segment.
7-controllerpcb
1. On the back side of the **Conductor and Digit 1** PCB, align the colon segment so its square base is positioned into the square hole of the PCB.
8-controllerpcb
1. Solder the 3mm LEDs into place.
9-controllerpcb
1. Optionally you can use a metric ruler to verify the LEDs protrude perpendicular from the PCB and are 14mm from the PCB to the top of the lens of the LED. This optional step insures the proper length of the 3mm LEDs.
10-controllerpcb

## PNP and NPN transistors

1. Following the picture below, solder the **s8550D PNP transistor** into the through hole (mis-) labelled `Q3 2N8550` on the front face of the **Conductor and Digit 1** PCB. When inserting the transistor's pins into the through holes, be sure to orient the transistors so the flat face matches the silk screen on the PCB as held by the tweezers in the picture.
4-controllerpcb
1. Following the picture below, solder the **2N2222A PNP transistor** into the though hole labelled `Q2 2N2222` on the front face of the **Conductor and Digit 1** PCB.
5-controllerpcb

## Headers for the Pico and PicoW

On the back side of the PCB, place the four 20 pin headers into the through holes for `RASP1` and `RASP2`. Carefully turn over the PCB while keeping the 20 pin headers in the through holes. Level the PCB and adjust the two 20 pin headers so they are perpendicular to the PCB. To keep the headers perpendicular to the PCB, you can provide a temporary solder onto a pin or use a jig. Solder the pins once in place. Snip all the pins flush, resolder each to a smooth bead, then remove the flux with cotton dabbed with isopropyl alcohol.
11-controllerpcb

## Surface mount resistors

On the back side of the PCB, solder the two 10kΩ resistors onto the pads marked `R2 10k` and `R3 10k` located between the top and bottom rows of the 20-pin headers. Soldering surface mount components require a slightly different skill than through hole soldering as you'll need to use tweezers to center the resistor over the pads and apply a minimal amount of solder.
12-controllerpcb

## Install Six, two pin (2P) Terminal Block Connectors

There are five 2P terminal block connectors on the front face of the PCB, and one on the back side.
The picture below shows a completed install of the terminal block connectors on the front face of the **Conductor and Digit 1** PCB. Note the arrows pointing in the direction of the terminal block connector where the wires are inserted into the ports. To follow the steps below, you'll position the front face of the **Conductor and Digit 1** PCB up, then work your way from the bottom left corner **(1)**, to the bottom right corner **(5)**.
13-controllerpcb

1. Follow the picture below and insert the 2P terminal block connector into the `5v-D1` through holes with the connector facing LEFT, then solder it into place.
14-controllerpcb
1. Follow the picture below and insert the 2P terminal block connector into the `U7, Tx-1 Rx-1` through holes with the connector facing LEFT, then solder it into place.
15-controllerpcb
1. Follow the picture below and insert the 2P terminal block connector into the `U7, GPIO19 Tx-0 `through holes with the connector facing LEFT, then solder it into place.
16-controllerpcb
1. Follow the picture below and insert the 2P terminal block connector into the `UART1, Tx-0 Rx-0` through holes with the connector facing RIGHT, then solder it into place.
17-controllerpcb
1. Follow the picture below, insert the 2P terminal block connector into the `5v-D0` through holes with the connector facing LEFT, then solder it into place.
18-controllerpcb
1. Position the back of the PCB up and insert the 2P terminal block connector into the `5v-OUT` through holes with the connector facing RIGHT, then solder it into place.
19-controllerpcb

## Electrolytic and Ceramic Capacitors

1. On the front of the **Conductor and Digit 1** PCB, align the electrolytic capacitor `-` sign opposite the `+` printed on the PCB for capacitor `c01` and `c1`, see the picture below. Insert the pins into the through holes, then turn the **Conductor and Digit 1** PCB over to the back side and solder the capacitors.
20-controllerpcb
1. On the front of the **Conductor and Digit 1** PCB, insert the ceramic capacitor pins into the through holes titled `c02` and `c2`. Ceramic capacitors are non-polarized and can be inserted in either direction. Turn the **Conductor and Digit 1** PCB over to the back and solder the capacitors.
21-controllerpcb

## Mount the Motor Drivers

On the front face of the **Conductor and Digit 1** PCB, [mount the L293D 16-pin IC Stepper Motor Drivers](digitpcbassembly.md/#mount_the_motor_drivers) as previously completed for the digit PCBs.
5-controllerpcb-motordriverIC

## Vertical Slide SPDT Switch

On the back of the **Conductor and Digit 1** PCB, insert the SPDT vertical slide switch pins into the `ON/OFF` through holes found on the top right hand corner, then solder into place.
22-controllerpcb

## Light Dependent Resistor (LDR)

Following the picture below and from the back of the **Conductor and Digit 1** PCB, place the two LDR pins into the `R1` through holes. Bend the pins of the LDR upward so the head of the LDR fits tightly on the top of **Conductor and Digit 1** PCB. Solder the LDR in place once properly positioned.

23-controllerpcb

Congratulations, you've completed assembling the controller and digit 1 PCB!

## Conductor and Digit 1 Schematic

The schematic in this section (below) represents the **Colons & Display Microcontroller** portion of the circuit for the **Conductor and Digit 1** PCB. This circuit is designed to control the colons of the display, acting as the central hub for communication, power management, and environmental data (interior and outdoor) integration. The Raspberry Pi Pico W 2040 orchestrates all operations, while the supporting components ensure stable and efficient functionality. Below is an explanation of the various components, their purpose, and how the circuitry functions:

### *Key Components and Their Purpose*

1. **Raspberry Pi Pico W 2040 (Microcontroller)**:</br>
    *Purpose*: Acts as the central processing unit for the display. It controls the colons and communicates with the digits.</br>
    *Functions*:
      - Sends commands to the digits (e.g., what to display, brightness levels).
      - Manages `Wi-Fi connectivity for remote control and time synchronization.
      - Handles scheduling for displaying time, date, and environmental data.
      - Controls power-saving modes by turning off unused digits.
2. **4-Pin UART and Low Power mode pin connector (U7)**:</br>
    *Purpose*: Provides communication between the microcontroller and the digits via UART (Universal Asynchronous Receiver-Transmitter).</br>
    *Pins*:
       - `Tx-0`, `Rx-0`, `Tx-1`, `Rx-1`: Used for transmitting and receiving data to/from the digits.
       - `GPIO19`: is used to turn on and off the power to the digits.
3. **L293D Motor Driver IC (U5)**:</br>
    *Purpose*: Drives the colon motors (top and lower colons) to control their movement.</br>
    *Functionality*: Allows the microcontroller to control the colon motors for precise positioning.</br>
    *Pins*:
     - `ENABLE1` and `ENABLE2`: Controls the motor speed.
     - `INPUT1`, `INPUT2`, `INPUT3`, `INPUT4`: Control the CW and CCW direction of the motors.
     - `OUTPUT1`, `OUTPUT2`, `OUTPUT3`, `OUTPUT4`: Provide the output signals to the motors.
4. **2-Pin Terminal Block Connectors**:</br>
    *Purpose*: Provide connections for external components like power, UART communication, and sensors.</br>
    *Examples*:
     - `5V-D1`, `5V-D0`: Power connections for the digits.
     - `UART1`, `Tx-0`, `Rx-0`: UART communication lines.
     - `5V-OUT`: Power output for external components.
5. **PNP and NPN Transistors (S8550 and 2N2222)**:</br>
    *Purpose*: Act as a switch for powering the DHT22 sensor.</br>
    *S8550 (PNP)*: Used for switching power on or off to the DHT22 sensor</br>
    *2N2222 (NPN)*: Used to drive the base of the S8550 to manage power to the DHT22 sensor.
6. **Light Dependent Resistor (LDR)**:</br>
    *Purpose*: Measures ambient light levels to adjust the brightness of the display dynamically.</br>
    *Placement*: Connected to `R1` and works with the microcontroller to sense light intensity.
7. **Electrolytic and Ceramic Capacitors (C01, C1, C02, C2)**:</br>
    *Purpose*: Provide power filtering and decoupling to ensure stable operation of the microcontroller.</br>
    *Electrolytic Capacitors*:</br>
     - Polarized, used for smoothing power supply fluctuations.
    *Ceramic Capacitors*:</br>
     - Non-polarized, used for high-frequency noise filtering.
8. **Vertical Slide SPDT Switch (SW1)**:</br>
    *Purpose*: Acts as an on/off switch for the entire circuit where off may be **Low Power** or **Admin** mode. When the switch is on and the 12v power supply is plugged in, the display will run using its saved settings which includes the SSID and password to the wifi network. When the switch is turned off, the disconnected 12v power supply is then connected and plugged into wall power, the Pico W provides its own wifi and web service allowing you to direcctly connect to its web page and remotely change the display settings. When the switch is changed to the off position while the display is actively running, then the display will retract all the segments and enter low power mode.</br>
    *Placement*: Controls its internal wifi service and the flow of power to the display.
9. **Resistors (R2, R3)**:</br>
    *Purpose*: Limit current and set voltage levels in the circuit.</br>
    *R2 and R3 (10kΩ)*: Pull-up or pull-down resistors for stabilizing signals.
10. **LEDs (TOP-LED1, LWR-LED1)**:</br>
    *Purpose*: Indicate the status of the colons.</br>
    *Placement*: Positioned on the PCB to align with the colon segments.
11. **DHT22 Sensor Connector**:</br>
    *Purpose*: Provides a connection for the Digital Humidity and Temperature (DHT) sensor.</br>
    *Functionality*: Allows the microcontroller to read environmental data for display.

### *How the Circuitry Works*

1. **Power Supply**:</br>
      - Power is supplied by buck converters through the `5V-OUT` and `5V-D1/D0` terminal blocks.
      - Capacitors (C01, C1, C02, C2) stabilize the power supply and filter noise for the microcontrollers.
1. **Microcontroller Control**:
      - The Raspberry Pi Pico W 2040 serves as the brain of the circuit, controlling all components.
      - It communicates with the digits via UART (U7) and controls the colon motors through the L293D motor driver (U5).
1. **Colon Motor Control**:
      - The L293D motor driver receives control signals from the microcontroller to drive the colon motors.
      - The `ENABLE` and `INPUT` pins determine the speed and direction of the motors.
1. **Display Brightness Adjustment**:
      - The LDR (R1) measures ambient light levels and sends the data to the microcontroller.
      - The microcontroller adjusts the brightness of the LEDs accordingly.
1. **Wi-Fi and Scheduler**:
      - The Raspberry Pi Pico W 2040 connects to a Wi-Fi network to synchronize time and fetch weather data.
      - The scheduler manages the display of time, date, and environmental data.
1. **Low Power Mode**:
      - The microcontroller uses the S8550 and 2N2222 transistors to switch off power to the DHT22 when not in use.
1. **User Interaction**:
      - The SPDT switch (SW1) allows the user to turn the circuit on or off (low power or Admin mode).
      - The LEDs provide visual feedback for the status of the colons.

controllerschematic-1

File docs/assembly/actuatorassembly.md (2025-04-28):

# Actuator Assembly

There are 30 actuators in the display, 7 per digit and 2 for the colons (4 digits x 7 segments + 2 colons = 30 total actuators). The actuator assembly includes installing the shaft gear onto the DC brushed motor, preparing and adding wires to the motor, assembling the motor mount, pinion gear, and shaft, then adding the DC brushed motor to the assembled motor mount. The picture below shows a fully assembled actuator.

actuatorstep11

## Prerequisites

- Nylon pinion gear 30, `digit-gear30.stl`
- Black Matte PLA shaft gear 10, `digit-gear10.stl`
- White Matte PLA motor mount, `digit-motor-mount.stl`

!!! tip
    Ensure all 3D-printed parts are free of defects and printed with the recommended settings for optimal fit and durability.

***Table of components***

| Quantity | Component | Image |
| :--: | :---| :-----: |
| 30 | 130 Strong Magnetic Toy Motor | component-10 |
| 150 cm | 28 AWG Stranded Wire (white) | component-11 |
| 150 cm | 28 AWG Stranded Wire (black) | component-12 |
| 60 | DuPont 2.54mm Pitch Female Connector Pin | component-13 |
| 30 | DuPont 2.54mm Pitch Terminal Connector Single Row Housing 2 Pin | component-14 |
| 10 | Jumbo Metal Paperclip (smooth) | component-15 |

***Table of tools***

| Required | Tool | Image |
| :---: | :--- | :---: |
| Yes | Soldering station | tool-4 |
| Yes | 0.8mm 1.76oz RoHS flux core solder | tool-1 |
| Yes | Large regular tipped screwdriver | tool-7 |
| Yes | Super glue | tool-8 |
| Yes | 22-34 AWG Wire Stripper and Cutter | tool-9 |
| Yes | Pin Crimp Tool for 2.54mm Dupont Connectors | tool-10 |
| Yes | Heavy Duty Wire Cutter Pliers | tool-11 |
| Yes | Heavy Duty Cross Locking or Clamping Tweezers | tool-12 |
| Yes | 10cm zinc strip | tool-14 |
| No | Label Maker (optional for labeling wires) | tool-5 |

## Shaft Gear

In this section, you'll glue the shaft gear onto the motor shaft to prevent slippage. The shaft gear must be made from rigid filament like PLA or ABS.

!!! warning
    Always work in a well-ventilated area when soldering or using super glue to avoid inhaling fumes.

### Shaft Gear Installation Steps

The tools and parts needed include: a regular tipped screwdriver, super glue, `digit-gear10.stl`, and a DC brushed toy motor.

1. **Apply Glue**: Add a drop of super glue to the shaft gear. Ensure the gear is 10mm high with a 5mm hole. Avoid excess glue to prevent it from seeping into the motor shaft.
   shaftstep1
1. **Attach the Gear**: Position the DC motor vertically so the bottom of the shaft rests on a hard surface. Use the screwdriver to press the gear 5mm down onto the shaft. Ensure the gear is aligned and does not wobble.
   shaftstep2
1. **Repeat**: Follow these steps for the remaining 29 motors. Allow the glue to cure for at least 10 minutes before proceeding.
   shaftstep4

## Wires

The white 28 AWG wire provides clockwise (CW) motion to extend the segment, while the black wire provides counterclockwise (CCW) motion to retract it.

### Wire Cutting and Soldering Steps

1. **Cut Wires**: Cut 9 white and 9 black wires to 6cm for actuators labeled "C", "D", and "UC" (upper colon). Cut 21 white and 21 black wires to 4cm for the remaining actuators. Use a ruler for precise measurements.
   step1
1. **Strip Wires**: Strip 3mm of insulation from one end of each wire. Avoid nicking the wire strands.
   step2
1. **Prepare Terminals**: Position the motor with the shaft pointing away and terminals facing up. Heat the soldering iron to 350°C and tin each terminal with a small amount of solder.
   step3
1. **Solder Wires**: Solder the white wire to the left terminal and the black wire to the right terminal. Ensure the solder joints are clean and secure.
   step4

!!! tip
    Use a helping hand tool to hold the motor steady while soldering.

!!! note
    Label the black-wire side of the 6cm actuators ("C", "D", and "UC"). No labels are needed for the 4cm actuators.

### Dupont Connections

1. **Strip Wires**: Strip 3mm of insulation from the free end of each wire.
   step1
1. **Crimp Connectors**: Attach female Dupont connectors to each wire.
   step2
1. **Attach Housing**: Slide the wires into the Dupont connector housing until the pins lock in place.
   step3
1. **Repeat**: Complete this process for all motors. Ensure labeled actuators are correctly marked.
   step4

!!! tip
    Test each connection from the Dupont connector to the soldered wire on the motor with a multimeter to ensure continuity before proceeding.

## Motor Mount

Properly assembling the motor mount is critical to avoid issues like jamming or sticking. The motor mount consists of:

- **(A)** Motor mount (`digit-motor-mount.stl`)
- **(B)** Pinion reduction gear (`digit-gear30.stl`)
- **(C)** Pinion gear shaft (cut from a jumbo paperclip)

Discard the red support section.

actuatorfigure

### Motor Mount Assembly Steps

1. **Cut Shaft**: Cut straight sections from a jumbo paperclip into 2cm pieces. Use heavy-duty wire cutter pliers for clean cuts.
   actuatorstep1
1. **Insert Shaft**: Insert the 2cm shaft into the motor mount until it protrudes 1mm into the pinion gear space. Ensure the shaft is straight.
   actuatorstep4
1. **Attach Pinion Gear**: Align the pinion gear hole with the shaft and slide it into the motor mount. Verify the gear rotates freely.
   actuatorstep5
1. **Melt Collar**: Heat the soldering iron to 250°C. Use a zinc strip to melt and flatten the collar onto the motor mount. Work carefully to avoid damaging the mount.
   actuatorstep7
1. **Verify Fit**: Ensure the shaft rotates freely in the pinion gear but is not loose. Reprint the gear if necessary to avoid jamming.
   actuatorstep9
1. **Install Motor**: Insert the prepared motor into the mount with the shaft pointing left and terminals downward. Secure the motor firmly.
   actuatorstep10
1. **Repeat**: Assemble the remaining 29 motors. Perform a final inspection to ensure all assemblies are consistent.

!!! warning
    Avoid overtightening or forcing components, as this may cause damage or misalignment.

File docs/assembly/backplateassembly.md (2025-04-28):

# Backplate and Stand Assembly

This guide details installing the backplate onto the display face, installing the DHT22 sensor, connecting the motor wires to the motor pins, and installing the stand and power manager onto the display face. Below is the back of the display when the backplates and stand are assembled.

backplateassembly-13

## Prerequisites

- Completed all the guides previous to this assembly guide, which include the digit PCBs, conductor and digit 1 PCB, power management PCB, and mounting the buck modules.
- `digit-back-plate.stl`
- `digit2-back-plate.stl`
- `digit1-back-plate.stl`

## Digit Backplate Assembly

The picture below shows the digit 0 and 3 backplates in an upright position. Note the segment characters, **A** through **G**, engraved onto the backplate. The round port holes allow the motor's rack gear to protrude into the face of the display. The rectangular holes allow the motor's white and black wires to plug into their respective `CW` and `CCW` pins on the PCB.

**digit-back-plate.stl**

backplateassembly-1

The picture below shows the digit 2 backplate. Digit 2 backplate is nearly the same as the backplates for digits 0 and 3 except for the stand mount hole as highlighted by the white box.

**digit2-back-plate.stl**

backplateassembly-2

1. Each motor is mounted to the backplate using three M1.7x8mm screws. Use a small philips tip screwdriver to install the motors. A larger philips tip screwdriver is prone to overtighten and may cause the head of the screw to shear off. The picture below shows the order the actuator motors should be installed.</p>
backplateassembly-3

2. Repeat the install for digits 2 and 3.

## Conductor and Digit One Backplate Assembly

The picture below shows the conductor and digit one backplate in an upright position. The backplate has engraved segment characters **A** through **G** and colons **U** and **L**. The large rectangular hole above the **U** label is where the on/off switch is mounted. Also note the top edge of the backplate has a slot for the LDR to fit into.

**digit1-back-plate.stl**

backplateassembly-4

The picture below shows the order the actuator motors should be installed.

backplateassembly-5

## Install the Backplates onto the Face

1. With the digit face pointing down, place the backplates into the slots on the back of the digit face.
backplateassembly-6
1. Each backplate is mounted to the face using M2x15mm screws. Use a medium sized philips tip screwdriver to install the backplates. The picture below shows the installation of the backplates onto the face.
backplateassembly-7
1. Using needlenose pliers, connect each of the motor's Dupont connector to their respective CW (white wire) and CCW (black wire) pins on the PCB.
backplateassembly-8
1. Trim the 3 wires that come with the DHT22 to a suitable length, then connect the Dupont connections to the appropriate sensor pins. Verify the wires connecting the `+ Data -` pins on the PCB are connected to the sensor's `+ Data -` pins.
backplateassembly-9
1. Using an M1.7x6mm self tapping screw, mount the DHT22 as shown in the picture below.
backplateassembly-10

## Install the Stand onto the Face

1. Place the notches in the stand into the groove on the face as shown in the picture below. Be sure not to pinch any of the power management wires while mounting the stand.
backplateassembly-11
1. Following the picture below, **(A)** attach the stand's vertical holder to the digit 2 backplate with an M1.7x8mm self tapping screw. **(B)** Attach the stand's side mounting tabs with M2x15mm self tapping screws.
backplateassembly-12
1. Set the digit upright on the stand. See be picture at the beginning of this guide to verify the completed assembly of the backplates and stand.

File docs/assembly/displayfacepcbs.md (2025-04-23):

# Display Face and PCBs Assembly with Integration Testing

This guide details assembling the PCBs onto the display face and includes integration testing of the electronic components that make the Kinetic Display function.

## Prerequisites

- Completed assembly of all PCBs, including the conductor, digit, and power management PCBs.
- Wired and calibrated buck modules.
- Installed UART and relay wiring.

***Table of components***

| Quantity | Component | Image |
| :--: | :--- | :-----: |
| 30 | M1.7x8mm Cross Round Head with Washer Self Tapping Screw 304 Stainless Steel Screws | component-32 |

***Table of tools***

| Required | Tool | Image |
| :---: | :--- | :---: |
| Yes | Fine-tipped Philips head screwdriver | tool-17 |

## Display Face and PCBs Assembly

1. Connect the two 3D-printed sides of the display face with the front facing down onto your workbench. The cove on the backside of the display face should be on the top, furthest from you. See the picture in the next step with the conductor PCB tilted upward to unveil the position of the cove.
1. Position the stand and PCBs atop the display face as shown in the picture below. Ensure the wiring fits in the cove and the gaskets of the PCBs are flush against the display face without any wires protruding.  
   displayfacepcb-1
1. Using a small Philips head screwdriver, secure the PCBs with M1.7x8mm self-tapping screws in the locations highlighted below.  
   displayfacepcb-2
1. Following the picture below:
      - **(A)** Connect the DHT22 sensor to the conductor PCB.
      - **(B)** Plug in the 12V power supply into the power management PCB's barrel jack. Note: The DHT22 sensor connection is temporary and will be permanently installed later.
      - **(C)** Connect your computer's USB cable to the conductor PCB Raspberry Pi Pico W 2040.  
   displayfacepcb-3

!!! warning
    ONLY connect your computer's USB cable to the conductor PCB Raspberry Pi Pico W 2040 AFTER plugging in the 12V power supply. Plugging in your computer's USB cable BEFORE your 12V power supply is plugged in will burn out the sensitive circuitry within the Pico W.

## Integration Test

1. From Visual Studio Code on your computer:
      - **(A)** Click the `_main.py` file in the explorer pane.
      - **(B)** Run the program. Ensure you have a connection via your computer's USB cable to the conductor PCB Raspberry Pi Pico W 2040.  
   displayfacepcbtest-1
1. From Visual Studio Code on your computer, type the `(a)ll digits test` command in the terminal to check the UART connections across the digits. See the video below to verify the segments animate from digit 3 to digit 0.  
   displayfacepcbtest-2  
   alldigitstest
1. From the command terminal pane, use the `(r)elay (0=off,1=on)` command by typing `r0` (off) then `r1` (on) to check the relay functionality. See the video below with the LEDs on the buck converters turning on and off.  
   displayfacepcbtest-3  
   relaytest
1. From the command terminal pane, use the `(t)emp(0=C,1=F)` command by typing `t0` or `t1` to display the temperature (respectively) in Celsius or Fahrenheit. You'll need to tip the display up on one side to view the front of the display as shown in the video below.  
   displayfacepcbtest-4  
   temperaturetest
1. From the command terminal pane, use the `(l)uminosity` command while shielding the LDR with your hand (or turning off the light in your room). You won't see any command output, only a change in the brightness of the display. If the LED colons are brighter or dimmer than the digit LEDs, adjust the `LEDbrightnessFactor` setting in the `digit_colons.py` file. Presently, the LED colons are set to about 1/3rd the power of the digit LEDs. After making changes to the `LEDbrightnessFactor`, upload the updated file to the controller's Raspberry Pi Pico W 2040.  
   displayfacepcbtest-5  
   brightnesstest
1. From your Visual Studio Code file explorer pane:
    Open the `secrets.py` file and change the `usr` and `pwd` to your network SSID and password so the Kinetic Display can connect to your local Wi-Fi network. This step is optional and can be done later.
1. At the bottom of the `_main.py` file:
      - Comment out the `manual()` call and uncomment the `loop()` call.
      - Rename `_main.py` to `main.py`.
      - Upload the project to the controller's Raspberry Pi Pico W 2040.

!!! warning
    Forgetting to upload the renamed `main.py` file to the controller's Raspberry Pi Pico W 2040 will cause the Kinetic Display to be unresponsive.

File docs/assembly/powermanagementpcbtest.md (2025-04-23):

# Power Management PCB Test

Run the tests in this section after assembling the power management PCB. Any defective electronic component on the power management PCB will need to be replaced before completing the project.

## Prerequisites

- [Completed the controller and digit 1 PCB assembly](./controllerpcbassembly.md).
- [Completed power management PCB](./powermanagementpcb.md).
- Computer and microcontroller with the [prerequisite software](../prerequisitesoftware.md).
- 3 male-male jumpers (or wires with the ends stripped and tinned with solder).

## Test Relay

1. Following the picture below on the BACK of the controller and digit 1 PCB:
    **(A)** Using a pair of jumper wires, connect the positive (+) and negative (-) ports of the terminal block connector `5v-OUT` to the **(B)** positive (+) and negative (-) ports on the corresponding terminal block connector marked `CONN-1` on the power management PCB.  
   powermanagement-1
1. Using a single jumper wire:
    **(A)** Connect the `GPIO19` port of the terminal block connector in `CONN-1` on the power management PCB to **(B)** the `GPIO19` port of the terminal block connector on the FRONT face of the controller and digit 1 PCB.  
   powermanagement-2
1. Following the picture below, connect a USB cable from your computer to the Raspberry Pi Pico W on the BACK of the controller and digit 1 PCB.  
   powermanagement-3
1. From your computer, open a terminal session using Visual Studio Code:
      - Select `MicroPico vREPL` from the terminal dropdown menu.
      - Once connected, type (or copy/paste each line) the following code into the terminal window:

```python
    from machine import Pin

    p = Pin(19, Pin.OUT)
    p.on()
```

   - Once you hear the relay click to connect the circuit, type the following code into the terminal window:

```python
    p.off()
```

   Below is a screenshot of the terminal session:  
   powermanagement-4

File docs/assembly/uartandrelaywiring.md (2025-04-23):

# UART and Relay Wiring

UART (Universal Asynchronous Receiver-Transmitter) facilitates communication between the conductor and the digit PCBs. The conductor acts as the central hub, transmitting commands and receiving status updates from the digits.

1. **Conductor (Transmitter and Receiver)**:
      - The conductor's UART `Tx` (transmit) pin sends data to the digits, such as display commands and brightness levels.
      - The conductor's UART `Rx` (receive) pin listens for acknowledgment or status updates from the digits.
2. **Digits (Receivers and Transmitters)**:
      - Each digit PCB's UART `Rx` pin receives commands from the conductor.
      - The digit PCBs' UART `Tx` pins send status updates or responses back to the conductor.

This bidirectional communication ensures synchronized operation of the display, enabling the conductor to manage all digits effectively.

## UART Wiring

The UART wiring diagram illustrates the communication connections between the conductor and the digit PCBs. It shows how the UART `Tx` (transmit) and `Rx` (receive) pins are connected using the two UART channels 0 and 1.

- The conductor's channel 1 `Tx` pin is connected to the channel 1 `Rx` pin on the digit 2 PCB. The conductor PCB has tracing that connects the conductor's channel 0 `Tx` pin to channel 0 `Rx` pin on digit 1.
- The conductor's channel 1 `Rx` pin is connected to the channel 1 `Tx` pin of the digit 2 PCB. The conductor PCB has tracing that connects the conductor's channel 0 `Rx` pin to channel 0 `Tx` pin on digit 1.
- Digit 2 and 3 PCBs' `Tx` pins are connected, and Digit 0 PCB and Digit 1 on the conductor PCB's `Tx` pin are connected. The same is true for the `Rx` pins for Digits 0-3.

uartwiring

Note: The wire color references in the section below are yellow and blue, which can be substituted with white and black.

1. Follow the picture below for Digit 0 and 1 UART wiring. On Digit 0 PCB:
      - **(A)** Connect the yellow (white) wire to the `Rx-0` and the blue (black) wire to the `Tx-0` terminal block connector.
      - Route the wires to the Digit 1 `Rx-0` and `Tx-0` terminal block connectors, leaving about 10mm of extra length, then cut.
      - **(B)** Slide the heat shrink over the wires and position them according to the picture.
      - On Digit 1 PCB, **(C)** connect the yellow (white) wire to the `Rx-0` and the blue (black) wire to the `Tx-0` terminal block connector.  
   uartwiring-1
2. Follow the picture below for Digit 2 and 3 UART wiring. On Digit 2 PCB:
      - **(A)** Connect the yellow (white) wire to the `Rx-1` and the blue (black) wire to the `Tx-1` terminal block connector.
      - Route the wires to the Digit 3 `Rx-1` and `Tx-1` terminal block connectors, leaving about 10mm of extra length, then cut.
      - **(B)** Slide the heat shrink over the wires and position them according to the picture.
      - On Digit 3 PCB, **(C)** connect the yellow (white) wire to the `Rx-1` and the blue (black) wire to the `Tx-1` terminal block connector.  
   uartwiring-2
3. Follow the picture below for the conductor to Digit 2 UART wiring. On the conductor PCB:
      - **(A)** Connect the yellow (white) wire to the `Rx-1` and the blue (black) wire to the `Tx-1` terminal block connector.
      - Route the wires to the Digit 2 `Rx-1` and `Tx-1` terminal block connectors, leaving about 10mm of extra length, then cut.
      - On Digit 3 PCB, **(C)** connect the yellow (white) wire to the `Tx-1` and the blue (black) wire to the `Rx-1` terminal block connector.  
   uartwiring-3

## Relay Wiring

1. Follow the picture below starting from the back side of the conductor PCB:
      Using any color 28 AWG wire, connect the **(A)** terminal block connector pin `GPIO19` from the conductor PCB to the **(B)** terminal block connector pin `GPIO19` on the power management PCB.  
   relaywiring-1
1. Following the picture below, turn the conductor PCB over so the front face is up:
      - **(A)** Strip 3mm of insulation, then tin the stripped end with solder.
      - Connect the white wire to the `+` on the `5v-OUT` terminal block connector and the black wire onto the `-`.
      - **(B)** Route the white wire to the `5v +` and the black wire to the `5v -` on the power management PCB, then cut the wires with at least 2cm of slack.
      - Strip 3mm of insulation, tin the stripped end with solder, then connect each wire to the appropriate terminal block connector.  
   relaywiring-2
1. Following the picture below:
      - Position the heat shrink and apply heat with a heat gun.
      - Add the two remaining M1.7x6mm self-tapping screws to the power management PCB.
      - Ensure all 4 screws securing the power management PCB are snug, but do not overtighten.  
   relaywiring-3

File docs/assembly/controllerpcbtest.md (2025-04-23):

# Conductor PCB Test

Run the tests in this section after assembling the conductor PCB to ensure all the components on the PCB are soldered and functional. Any defective electronic component on the conductor PCB will need to be replaced before completing the project.

## Prerequisites

- [Completed Conductor and Digit 1 PCB ready for actuators](controllerpcbassembly.md).
- Computer and microcontroller with the [prerequisite software](../prerequisitesoftware.md).
- [Deployed the Conductor Project to the Conductor PCB](deploycontrollerproject.md).
- [Completed the digit PCB test](digitpcbtest.md) for digit 1 on the conductor PCB.

## Test the LED and Motor Segments

1. From Visual Studio Code:
      - **(A)** Select the **File -> Open Folder** menu.
      - **(B)** Select the conductor folder.
      - **(C)** Click the **Select Folder** button.  
   testpcbactuator-prerequisite
1. On the Conductor and Digit 1 PCB:
      - **(A)** Plug the USB cable from your computer into the USB port on the Raspberry Pi Pico W 2040.
      - **(B)** Connect a motor actuator to the `TOP-LED1` with the white wire Dupont connector plugged into the `CW` pin and the black wire plugged into the `CCW` pin.  
   controllerpcbtest-2
1. From Visual Studio Code:
      - **(A)** Select the `digit_colon.py` file.
      - **(B)** Select **MicroPico vREPL** from the terminal pane menu.  
   controllerpcbtest-3
1. From the Visual Studio Code status bar:
      - **(A)** Verify the Raspberry Pi Pico W is connected.
      - **(B)** Click the **Run** button to start the conductor PCB test application.  
   controllerpcbtest-4
1. The console test application shows various options that relate to the top or bottom colon:
      - The `TOP-LED1` is 0, and the `LWR-LED1` is 1.
      - Extend `TOP-LED1` by typing **e0** in the console.  
   controllerpcbtest-5
1. Following the picture below:
      - The `TOP-LED1` LED lights up, and the motor briefly turns on.
      - From the terminal session, type **r0** to retract the `TOP-LED1`.  
   controllerpcbtest-6
1. Repeat steps 5 and 6 for `COLON-LWR`.
1. Unplug the USB from the Raspberry Pi Pico W 2040 upon completion.

## Test the Light Detection

1. On the Conductor and Digit 1 PCB:
   Plug the USB cable from your computer into the USB port on the Raspberry Pi Pico W 2040.
1. From Visual Studio Code:
      - **(A)** Select the file `photoresistor.py`.
      - **(B)** Click the **Run** button in the status bar.  
   LDRpcbtest-1
1. The terminal pane will print the light level, ranging between 0 and 9, depending on the brightness of the light detected by the LDR.  
   LDRpcbtest-2
1. Unplug the USB from the Raspberry Pi Pico W 2040 upon completion.

## Test the Humidity and Temperature

1. On the Conductor and Digit 1 PCB:
      - **(A)** Plug the USB cable from your computer into the USB port on the Raspberry Pi Pico W 2040.
      - **(B)** Connect the DHT22 sensor by ensuring the `- Data +` pins in the `DHT1` silk screen align with the `+ out -` pins on the DHT22 sensor.  
   dhtpcbtest-1
1. From Visual Studio Code:
      - **(A)** Select the file `dhttest.py`.
      - **(B)** Click the **Run** button in the status bar.  
   dhtpcbtest-3
1. Verify the output in the terminal shows the temperature and humidity readings.  
   dhtpcbtest-4
1. Unplug the USB from the Raspberry Pi Pico W 2040 upon completion.

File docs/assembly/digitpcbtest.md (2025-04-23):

# Digit PCB Test

Run the tests in this section after assembling each digit PCB to ensure all components are soldered correctly and functional. Any defective electronic component on the digit PCB must be replaced before completing the project.

## Prerequisites

- [Completed digit PCB ready for actuators](./digitpcbassembly.md)
- Computer and microcontroller with the [prerequisite software](../prerequisitesoftware.md)
- An [assembled actuator](actuatorassembly.md)

## Test the Motor and LED Segments

1. **Open the Deployed Project**:  
  From Visual Studio Code, open the deployed `digit` project.
     **(A)** Click the file menu, **(B)** select the `digit` folder, then **(C)** click the **Select Folder** button.  
testpcbactuator-prerequisite
1. **Connect the Raspberry Pi Pico**:  
      - Plug a USB cable from your computer into the Raspberry Pi Pico's USB port on the digit PCB.  
      - Open the **MicroPico vREPL** in the terminal dropdown as described in [Verify Micropython on your Raspberry Pi Pico](../prerequisitesoftware.md/#verify_micropython_on_your_raspberry_pi_pico).  
digitpcbtest-1
1. **Connect the Actuator**:  
      - Plug the Dupont connector from the actuator into the `SEG-A` pins.  
      - Ensure the **white wire** is connected to the `CW` pin and the **black wire** to the `CCW` pin.  
digitpcbtest-2
1. **Open the Test File**:  
  From Visual Studio Code, **(A)** click on the `digit.py` file, then **(B)** select the MicroPico vREPL from the terminal menu.  
digitpcbtest-3
1. **Run the Test Application**:  
      - **(A)** Verify the connection between your computer and the Raspberry Pi Pico.  
      - **(B)** Click the **Run** button to execute the test application for the digit PCB.  
digitpcbtest-4
1. **Test Segment A**:  
      - The console test application displays options for segments 0-6, corresponding to segments A-G.  
      - Extend `SEG-A` by typing **e0** in the console.  
digitpcbtest-6
1. **Verify Segment A**:  
      - The 4 `SEG-A` LEDs should light up, and the motor should briefly turn on.  
      - Retract `SEG-A` by typing **r0** in the console.  
digitpcbtest-7
1. **Test Remaining Segments**:  
      - Repeat steps 6 and 7 for `SEG-B` through `SEG-G` to verify all segments work as expected.  
      - Perform this test for all digit PCBs (0-3).

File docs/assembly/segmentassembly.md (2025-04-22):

# Segment Assembly and Installation

The digit segments and colons give the display its distinctive design. Each hollow segment lights up when extended and turns off when retracted, creating a satisfying clacking sound with every movement. Like a traditional seven-segment display, the segments are tilted at a 5-degree angle for a sleek appearance.

segment-assembly

| Ref | File |
| :---: | :---|
| **A** | `seg-a.stl` through `seg-g.stl` and `colon-seg.stl` |
| **B** | `rack-gear.stl` |
| **C** | `seg-pin.stl` |
| **D** | `rackgear-bumper.stl` |
| **E** | `rackgear-bumper-gasket.stl` |

## Assemble and Install Segments

This section guides you through assembling and installing all segments on the display. The image below shows the 3D-printed parts required for segment assembly.

segmentassembly-prep

1. **Insert the Rack Gear**. Slide the end of the rack gear with the smallest rectangular hole into the segment sleeve, as shown below.
   segmentassembly-1

1. **Secure the Rack Gear**. Use needlenose pliers to hold the segment pin. Insert the pin through the small rectangular hole in the segment sleeve and rack gear to secure it, as shown below.
   segmentassembly-2
1. **Install the Segment**. Place the segment into its designated location on the display. Ensure the segment slides easily into its bay. If it does not, ***do not force it into place***. Try a different location for the segment.
   segmentassembly-3
1. **Repeat for All Segments**. Follow the above steps to install all digit and colon segments.

## Assemble and Install the Rackgear Bumpers

1. **Attach the Gasket**. Push the rackgear bumper gasket into the square hole on the face of the rackgear bumper, as shown below.
   segmentassembly-4
2. **Position the Bumper**. Slide the front peg of the rackgear bumper into the rectangular hole on the rackgear ***opposite the pinion gear***. Installing it on the same side as the pinion gear will cause the actuator to jam when extended.
   segmentassembly-5
3. **Secure the Tail End**. Use needlenose pliers to gently push the tail end of the rackgear bumper into the rectangular hole, as shown below.
   segmentassembly-6
4. **Repeat for All Bumpers**. Follow the above steps to install all rackgear bumpers.
   segmentassembly-7

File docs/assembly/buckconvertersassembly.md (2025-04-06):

# Buck Converter Assembly

## Prerequisites

- 3D print the digit and controller TPU gaskets

## PCB and Stand Layout

This section ensures wiring for the PCBs is placed over the TPU gasket otherwise the wires will be sandwiched between the display face and the PCBs.

1. Remove the Raspberry Pi Pico and Pico W 2040 from the PCBs. We'll add these later when it is safe to do so.
1. Lay the PCBs face up with digit 0 on the far right and digit 3 on the far left. Position the stand below the PCBs so the barrel jack is between the controller/digit 1 PCB and digit 2 PCB.
1. Place the TPU gaskets on the PCBs. Note the TPU gasket for digit 2 differs slightly from digit 0 and 3 gaskets.

## Digit Wiring and Buck Converter

!!! warning
    Use anti static mats and ESD wristband and grounding wire for the remainder of the Kinetic Display electronics assembly.

This section details wiring the buck converter to the PCBs. Each buck converter must be calibrated to have a 5.0v to 5.1v output. The install of the buck converter and wiring starts with digit 0 on the far right, then digit 1, then the colons/controller. Next we'll start with digit 3 on the far left followed by digit 2.

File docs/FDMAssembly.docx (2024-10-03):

# Prerequisites

Complete the assembly of the printed circuit boards (PCB) and electric motor wire soldering.

# Face assembly

Print the display faces following the table of FDM settings below and press together.

Table 1. FDM settings

File Name | face-digit0-1.stl | face-digits2-3.stl
Description | Right side of display face | Left side of display face
Material | PLA | PLA
Color | White | White
Size | 1.75mm | 1.75mm
Temp (C) | 190-210 | 190-210
Quantity | 1 | 1
Per unit (g) | 340 | 315
Plate | Smooth | Smooth
Layer Height | 0.2 mm | 0.2 mm
Infill | 50% | 50%
Infill Pattern | Grid | Grid
Enable Support | Yes | Yes
Ironing | Top Surfaces | Top Surfaces


Figure 1. Back view of the display face

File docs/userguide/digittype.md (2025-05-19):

# User Guide - Table of Human and Alien Digit Type

| Human | Alien |
| :---: | :--- |
| h-0 | a-0 |
| h-1 | a-1 |
| h-2 | a-2 |
| h-3 | a-3 |
| h-4 | a-4 |
| h-5 | a-5 |
| h-6 | a-6 |
| h-7 | a-7 |
| h-8 | a-8 |
| h-9 | a-9 |
| h-A | a-A |
| h-B | a-B |
| h-C | a-C |
| h-D | a-D |
| h-E | a-E |

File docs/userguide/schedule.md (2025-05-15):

# User Guide - Schedule Creation and Management

The Kinetic Display includes a powerful scheduling system that controls what information is shown on your display and when it appears. This guide will help you understand how to create, customize, and manage your display schedules.

!!! tip "Key Points"
    - Scheduling is managed by the Conductor (Raspberry Pi Pico W 2040)
    - Custom schedules are created as JSON files
    - Add or remove schedules through the display's [web service settings](websettings.md)
    - Multiple schedules allow for different display behaviors for various situations

## How Scheduling Works

The scheduling system operates on three key concepts:

| Concept | Description |
|---|---|
| **Schedules** | Collections of timed events that determine the display behavior |
| **Event actions** | Specific display functions (showing time, date, temperature, etc.) |
| **Time triggers** | When each event should activate (using precise times or wildcards) |

By combining these elements, you can create dynamic display routines tailored to your needs.

## Core Components

### 1. Schedule Files

Each display can store multiple schedule configurations:

- **`schedule_0.json`**, **`schedule_1.json`**, **`schedule_2.json`**, etc.
- Each schedule file is a JSON document containing a list of `scheduledEvent` objects
- Multiple schedules allow you to save different display configurations for various situations

#### Schedule File Structure

A complete schedule JSON file has the following structure:

```json
{
  "title": "Schedule Name",              // Name shown in settings dropdown
  "scheduleDescription": "Description",  // Brief explanation of this schedule
  "scheduledEvent": [
    // Array of scheduled events (detailed below)
  ]
}
```

#### Event Structure

Each event defines **when** to trigger and **what** action to perform:

```json
{
  "hour": -1,    // Every hour (wildcard)
  "minute": 0,   // When minute is 0 (top of each hour)
  "second": 20,  // When second is 20
  "elapse": 9,   // Run for 9 seconds
  "event": 2     // Show the date (action #2)
}
```

#### Event Fields Explained

| Field | Purpose | Example Values |
|---|---|---|
| `hour` | Hour to trigger (0-23, or -1 for every hour) | `8`, `13`, `-1` |
| `minute` | Minute to trigger (0-59, or -1 for every minute) | `30`, `45`, `-1` |
| `second` | Second to trigger (0-59) | `0`, `15` |
| `elapse` | Duration in seconds | `5`, `10`, `30` |
| `event` | Action ID (see Event Actions table) | `1`, `2`, `9` |

### 2. The Scheduler System

The scheduling system uses these components to control your display:

- The `ScheduleLoader` class (`scheduler.py`) loads schedule files and creates a list of `scheduleInfo` objects
- The main loop (`uart_command.py`) continuously checks if the current time matches any scheduled events
- When a match occurs, the corresponding action is triggered for the specified duration

### 3. Time Matching Patterns

Using `-1` as a wildcard in time fields creates flexible scheduling patterns:

#### Every Hour

Set `hour: -1` to run at the same minute/second each hour

```json
{ "hour": -1, "minute": 30, "second": 0, ... }  // Runs at 30 minutes past every hour
```

#### Every Minute

Set `minute: -1` to run at the same second each minute

```json
{ "hour": -1, "minute": -1, "second": 0, ... }  // Runs at the start of every minute
```

#### Specific Time

Set exact values to run at a specific time each day

```json
{ "hour": 8, "minute": 0, "second": 0, ... }  // Runs at 8:00:00 AM
```

---

## Event Actions Reference

The `eventActions` class in `scheduler.py` defines all possible actions the display can perform:

| Value | Name | Description |
|---|---|---|
| 0 | nothing | Do nothing |
| 1 | displayTime | Show the current time |
| 2 | displayDate | Show the current date |
| 3 | displayIndoorTemp | Show indoor temperature |
| 4 | displayIndoorHumidity | Show indoor humidity |
| 5 | displayOutdoorTemp | Show outdoor temperature |
| 6 | displayOutdoorHumidity | Show outdoor humidity |
| 7 | updateOutdoorTempHumid | Update external temp/humidity sensor |
| 9 | hybernate | Enter hibernation mode |

You use the `event` field in each scheduled event to specify which action to perform.

---

## Building Your Schedule

### Step 1: Plan Your Display Routine

!!! question "Consider These Questions"
    - What information is most important at different times of day?
    - How long should each piece of information display?
    - Are there times when the display should turn off (hibernate)?
    - What pattern will make the information most useful to viewers?

### Step 2: Create Your Schedule File

Each schedule file contains an array of events. Start with this basic structure:

```json
{
  "title": "My Custom Schedule",
  "scheduleDescription": "Brief description of what this schedule does",
  "scheduledEvent": [
    { /* event 1 */ },
    { /* event 2 */ },
    // more events...
  ]
}
```

### Step 3: Add Specific Events

For each action you want to schedule, add an event object to the `scheduledEvent` array:

#### Example: Show Time Every Minute

This event displays the current time for 10 seconds at the start of every minute:

```json
{
  "hour": -1,     // Every hour
  "minute": -1,   // Every minute
  "second": 0,    // When second is 0
  "elapse": 10,   // Run for 10 seconds
  "event": 1      // Display time (action #1)
}
```

#### Example: Show Date at Regular Intervals

These events display the date for 25 seconds every 5 minutes:

```json
{
  "hour": -1,     // Every hour
  "minute": 0,    // When minute is 0
  "second": 15,   // When second is 15
  "elapse": 25,   // Run for 25 seconds
  "event": 2      // Display date (action #2)
},
{
  "hour": -1,     // Every hour
  "minute": 5,    // When minute is 5
  "second": 15,   // When second is 15
  "elapse": 25,   // Run for 25 seconds
  "event": 2      // Display date (action #2)
}
```

#### Example: Enter Hibernation at Night

This event puts the display into hibernation mode at 10:00 PM for 8 hours:

```json
{
  "hour": 22,     // At 10:00 PM
  "minute": 0,    // At minute 0
  "second": 0,    // At second 0
  "elapse": 480,  // Run for 480 minutes (8 hours)
  "event": 9      // Enter hibernation (action #9)
}
```

## Real-World Example: schedule_0.json

The `schedule_0.json` file is an "All Features" schedule that demonstrates how to use all display capabilities:

!!! example "schedule_0.json Structure"
    ```json
    {
      "title": "All Features",
      "scheduleDescription": "Time, date, month, internal and external temp and humid",
      "scheduledEvent": [
        {
          "hour": -1, "minute": -1, "second": 0, "elapse": 10, "event": 1
        },
        {
          "hour": -1, "minute": -1, "second": 45, "elapse": 10, "event": 1
        },
        {
          "hour": -1, "minute": 0, "second": 20, "elapse": 9, "event": 2
        },
        {
          "hour": -1, "minute": 10, "second": 20, "elapse": 9, "event": 2
        },
        {
          "hour": -1, "minute": 2, "second": 20, "elapse": 9, "event": 3
        },
        {
          "hour": -1, "minute": 24, "second": 20, "elapse": 9, "event": 3
        },
        {
          "hour": -1, "minute": 2, "second": 30, "elapse": 9, "event": 4
        },
        {
          "hour": -1, "minute": 24, "second": 30, "elapse": 9, "event": 4
        },
        {
          "hour": -1, "minute": 5, "second": 20, "elapse": 9, "event": 5
        },
        {
          "hour": -1, "minute": 25, "second": 20, "elapse": 9, "event": 5
        },
        {
          "hour": -1, "minute": 5, "second": 30, "elapse": 9, "event": 6
        },
        {
          "hour": -1, "minute": 25, "second": 30, "elapse": 9, "event": 6
        },
        {
          "hour": 22, "minute": 0, "second": 0, "elapse": 480, "event": 9
        }
      ]
    }
    ```

### Understanding the Schedule Pattern

This schedule creates a predictable pattern with:

1. **Time Displays**
      - At second 0 of every minute: Show time for 10 seconds
      - At second 45 of every minute: Show time for 10 seconds
2. **Date Displays**
      - At second 20 of minutes 0, 10, 20, 30, 40, and 50: Show date for 9 seconds
3. **Indoor Conditions**
      - At minute 2 and 24 of each hour, second 20: Show indoor temperature for 9 seconds
      - At minute 2 and 24 of each hour, second 30: Show indoor humidity for 9 seconds
4. **Outdoor Conditions**
      - At minute 5 and 25 of each hour, second 20: Show outdoor temperature for 9 seconds
      - At minute 5 and 25 of each hour, second 30: Show outdoor humidity for 9 seconds
5. **Hibernation**
      - At 10:00 PM (hour 22): Enter hibernation mode for 8 hours (480 minutes)

### Tips for Effective Schedules

- **Avoid overlapping events**: If multiple events match the same time, only one will run
- **Mind the timing**: Ensure your `elapse` times don't create unwanted overlaps. Gaps are OK and will only cause a pause in before displaying an action (time, temperature, etc) when powering up.
- **Use hibernation**: To save power, schedule hibernation during overnight hours
- **Balance information**: Rotate between different types of information for the best user experience
- **Consider patterns**: Create predictable patterns so users can anticipate when specific information will be displayed

---

## Managing Schedules Through the Web Interface

Once you've created a custom schedule JSON file, you can add it to your Kinetic Display using the web interface.

### Adding a New Schedule

1. Connect to your Kinetic Display's web interface as described in the [Web Settings](websettings.md) guide
2. On the settings page, click the **Add Schedule** button
3. In the dialog that appears:
   - Upload your JSON file using the file selector
   - The system will add it to the available schedules

   settings-1

### Selecting a Schedule

1. From the Schedule dropdown menu, select your preferred schedule
2. Click **Save** to apply the changes
3. Follow the prompted steps to restart the display

### Deleting a Schedule

If you no longer need a particular schedule:

1. Select the schedule from the dropdown menu
2. Click the **Delete Schedule** button
3. Confirm the deletion when prompted
4. Click **Save** to apply the changes

!!! note
    The system includes several pre-installed schedules that provide good starting points and fallback options.

### Tips for Schedule Management

- **Create multiple schedules** for different situations
- **Back up your custom schedules** before making significant changes
- **Test new schedules** thoroughly to ensure they work as expected
- **Start with a copy** of an existing schedule as a template for your custom schedules

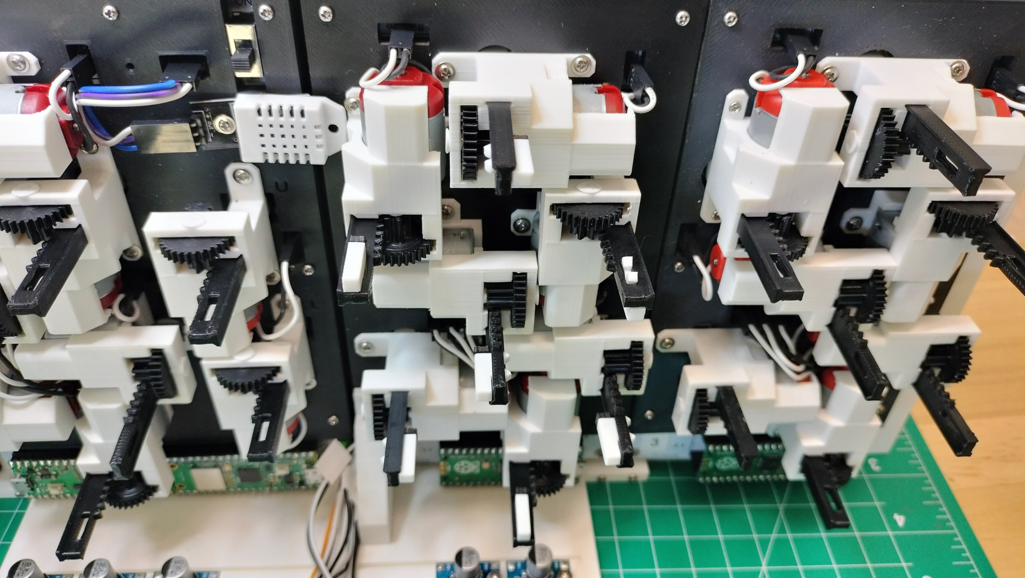
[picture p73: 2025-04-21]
docs/img/original/segmentassembly/segmentassembly-9.jpg

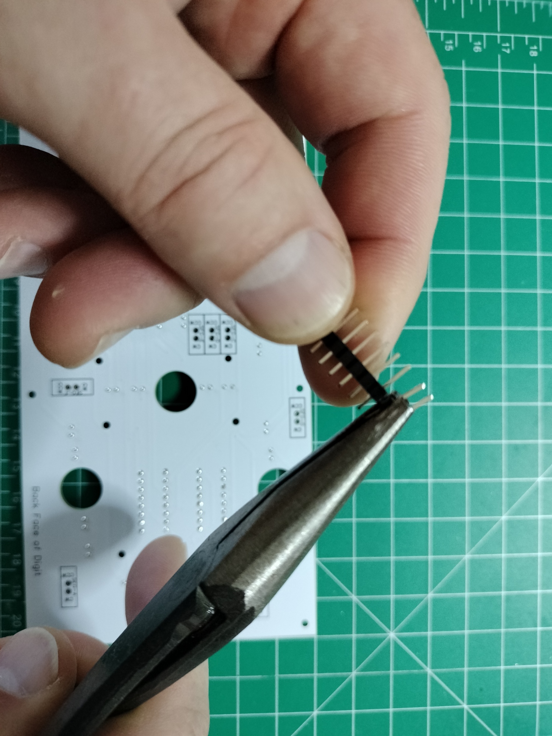
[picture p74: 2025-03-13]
docs/img/original/pcbassembly/2-digitpcbassembly-motorpins.jpg

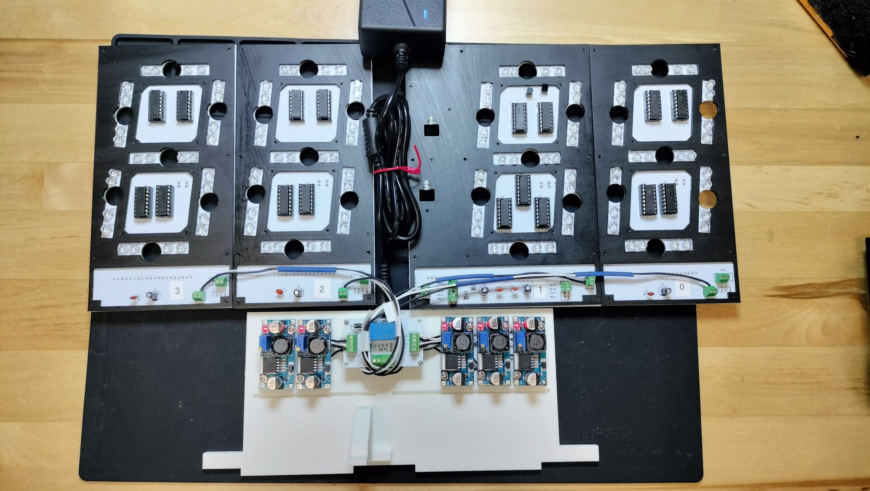
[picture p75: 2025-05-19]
docs/img/original/buckmoduleassembly/buckmoduleassembly-complete.jpg

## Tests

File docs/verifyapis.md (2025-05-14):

# Verify REST API Dependencies

The Kinetic Display uses several REST APIs to obtain local time and weather information. Use your computer's web browser to verify these APIs work for your location **before** ordering materials or 3D printing parts. Some APIs are used as backups for reliability, as they may be throttled or temporarily unavailable.

## Step 1: Get Your External IP Address

- Visit [http://api.ipify.org](http://api.ipify.org) in your browser. The page will display your external IP address (e.g., `11.115.204.194`). Save this address for the next steps.

## Step 2: Get Latitude, Longitude, and Time Zone

- Replace `{0}` in `http://ip-api.com/json/{0}` with your external IP address from Step 1.
- Example: [http://ip-api.com/json/11.115.204.194](http://ip-api.com/json/11.115.204.194)
- The JSON response should include `lat`, `lon`, and `timezone` fields. Example:

```json
{
  "status": "success",
  "country": "United States",
  "countryCode": "US",
  "region": "OH",
  "regionName": "Ohio",
  "city": "Whitehall",
  "zip": "43218",
  "lat": 39.9747,
  "lon": -82.8947,
  "timezone": "America/New_York",
  "isp": "DoD Network Information Center",
  "org": "DoD Network Information Center",
  "as": "AS749 DoD Network Information Center",
  "query": "11.115.204.194"
}
```

## Step 3: Get Weather Data

- Use the `lat` and `lon` values from Step 2 in the following API:
  `https://api.open-meteo.com/v1/forecast?latitude={0}&longitude={1}&current_weather=true&hourly=relativehumidity_2m`
- Example: [https://api.open-meteo.com/v1/forecast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](https://api.open-meteo.com/v1/forecast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)
- The JSON response should include `temperature` and `relativehumidity_2m` fields. Example:

```json
{
  "latitude": 39.986526,
  "longitude": -82.90847,
  "generationtime_ms": 0.0587701797485352,
  "utc_offset_seconds": 0,
  "timezone": "GMT",
  "timezone_abbreviation": "GMT",
  "elevation": 242,
  "current_weather_units": {
    "time": "iso8601",
    "interval": "seconds",
    "temperature": "°C",
    "windspeed": "km/h",
    "winddirection": "°",
    "is_day": "",
    "weathercode": "wmo code"
  },
  "current_weather": {
    "time": "2025-05-13T19:30",
    "interval": 900,
    "temperature": 21.3,
    "windspeed": 5.5,
    "winddirection": 122,
    "is_day": 1,
    "weathercode": 3
  },
  "hourly_units": {
    "time": "iso8601",
    "relativehumidity_2m": "%"
  },
  "hourly": {
    "time": [],
    "relativehumidity_2m": []
  }
}
```

## Step 4: Get World Time by IP

- Use your external IP address in the following API:
  `http://worldtimeapi.org/api/ip/{ip}`
- Example: [http://worldtimeapi.org/api/ip/11.115.204.194](http://worldtimeapi.org/api/ip/11.115.204.194)
- The JSON response should include a `datetime` field. Example:

```json
{
  "utc_offset": "-05:00",
  "timezone": "America/New_York",
  "day_of_week": 2,
  "day_of_year": 133,
  "datetime": "2025-05-13T16:42:11.694884-05:00",
  "utc_datetime": "2025-05-13T21:42:11.694884+00:00",
  "unixtime": 1747172531,
  "raw_offset": -21600,
  "week_number": 20,
  "dst": true,
  "abbreviation": "CDT",
  "dst_offset": 3600,
  "dst_from": "2025-03-09T08:00:00+00:00",
  "dst_until": "2025-11-02T07:00:00+00:00",
  "client_ip": "45.115.204.194"
}
```

## Step 5: Get Time API by IP

- Use your external IP address in the following API:
  `https://www.timeapi.io/api/Time/current/ip?ipAddress={ip}`
- Example: [https://www.timeapi.io/api/Time/current/ip?ipAddress=11.115.204.194](https://www.timeapi.io/api/Time/current/ip?ipAddress=11.115.204.194)
- The JSON response should include `year`, `month`, `hour`, `minute`, `seconds`, and `date`. Example:

```json
{
  "year": 2025,
  "month": 5,
  "day": 13,
  "hour": 15,
  "minute": 39,
  "seconds": 36,
  "milliSeconds": 804,
  "dateTime": "2025-05-13T15:39:36.8047099",
  "date": "05/13/2025",
  "time": "15:39",
  "timeZone": "America/New_York",
  "dayOfWeek": "Tuesday",
  "dstActive": true
}
```

## Step 6: Get World Time by Time Zone

- Use the `timezone` value from Step 2 in the following API:
  `http://worldtimeapi.org/api/timezone/{timezone}`
- Example: [http://worldtimeapi.org/api/timezone/America/New_York](http://worldtimeapi.org/api/timezone/America/New_York)
- The JSON response should include a `datetime` field. Example:

```json
{
  "utc_offset": "-05:00",
  "timezone": "America/New_York",
  "day_of_week": 2,
  "day_of_year": 133,
  "datetime": "2025-05-13T16:42:11.694884-05:00",
  "utc_datetime": "2025-05-13T21:42:11.694884+00:00",
  "unixtime": 1747172531,
  "raw_offset": -21600,
  "week_number": 20,
  "dst": true,
  "abbreviation": "CDT",
  "dst_offset": 3600,
  "dst_from": "2025-03-09T08:00:00+00:00",
  "dst_until": "2025-11-02T07:00:00+00:00",
  "client_ip": "45.115.204.194"
}
```

## Step 7: Get Time API by Time Zone

- Use the `timezone` value from Step 2 in the following API:
  `https://www.timeapi.io/api/Time/current/zone?timeZone={timezone}`
- Example: [https://www.timeapi.io/api/Time/current/zone?timeZone=America/New_York](https://www.timeapi.io/api/Time/current/zone?timeZone=America/New_York)
- The JSON response should include `year`, `month`, `hour`, `minute`, `seconds`, and `date`. Example:

```json
{
  "year": 2025,
  "month": 5,
  "day": 13,
  "hour": 15,
  "minute": 39,
  "seconds": 36,
  "milliSeconds": 804,
  "dateTime": "2025-05-13T15:39:36.8047099",
  "date": "05/13/2025",
  "time": "15:39",
  "timeZone": "America/New_York",
  "dayOfWeek": "Tuesday",
  "dstActive": true
}
```

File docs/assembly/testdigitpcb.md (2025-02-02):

# Digit PCB Test

Run the tests in this section after assembling each digit PCB to ensure all the components on the PCB are properly soldered into place and functional. Any defective electronic component on the digit PCB will need to be replaced before completing the project.

## Prerequisites

- Created a fork of the Kinetic-Display GitHub repository, see [Software and Microcontroller Preparation](../prerequisitesoftware.md#install-git-fork-and-clone-the-repository)
- Deployed the digit directory, also see [Software and Microcontroller Preparation](../prerequisitesoftware.md#install-git-fork-and-clone-the-repository)

## Configure and Deploy the Digit Project

1. Connect your Computer to the digit PCB Pico per the instructions on [Verify Micropython on your Raspberry Pi Pico](../prerequisitesoftware.md#verify-micropython-on-your-raspberry-pi-pico)
1. From VS Code, select **File->Open Folder...** and open the **deploy/digit** folder you deployed during step 4 in the section [Install Git, Fork and Clone the Repository](../prerequisitesoftware.md#install-git-fork-and-clone-the-repository)
2. Following the screen capture below, select the Explorer icon (**A**) in the left [Activity bar](https://code.visualstudio.com/docs/getstarted/userinterface#_basic-layout). Click the digit.json file (**B**) in the Explorer pane. Change the **"digit":** value (**C**) to match the PCB labelled number 0-3. ***It is very important to have the digit value match the PCB's labelled value.***
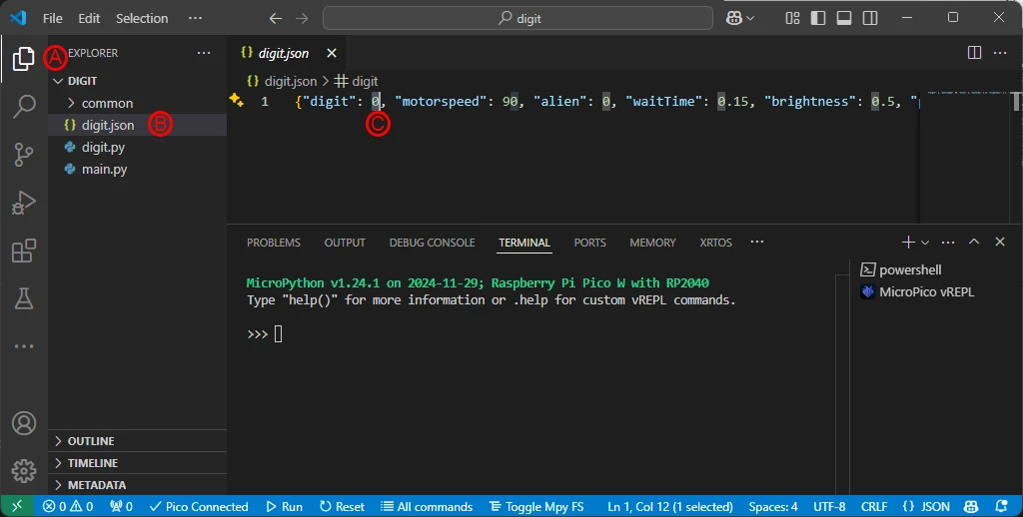
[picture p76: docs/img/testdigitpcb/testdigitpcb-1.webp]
testdigitpcb-1

1. Following the screen capture below, click **All Commands** (**A**) on the [status bar](https://code.visualstudio.com/api/ux-guidelines/status-bar). In the Command text field (**B**), type "**Upload**" after "**> MicroPico:** ", then select the dropdown **MicroPico: Upload project to Pico**.
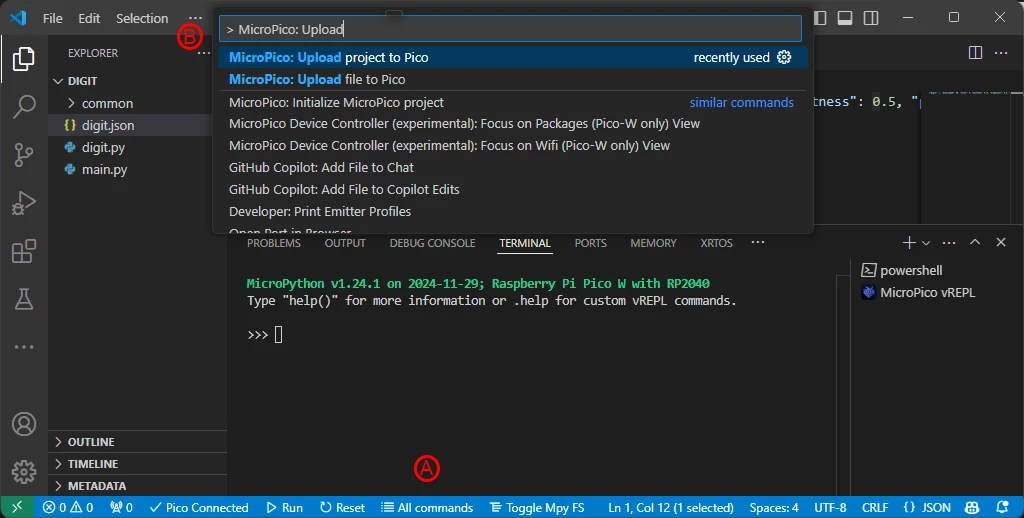
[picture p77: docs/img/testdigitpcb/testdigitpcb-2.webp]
testdigitpcb-2

1. Verify the project was uploaded into the Pico.

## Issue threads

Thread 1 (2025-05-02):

0805 Resistor spec

Osophoso, 2025-05-02:
0805 specification do not appear consistent between BOM and Power Management PCB Assembly Section.

in BOM specification:
10K ohm 0805 Resistor 1/4w Metal Film Fixed Resistor

in Power Management PCB Assembly
1K ohm 0805 Resistor 1/2w Metal Film Fixed Resistor

Which is the correct specification?

gobbyo, 2025-05-13:
It appears to be inconsistent everywhere and should be 1k ohm 0805 resistor 1/4w. Corrected.  Good find.

gobbyo, 2025-05-13:
Updated BOM and materials list in the assembly instructions for the power management PCB.

Closed 2025-05-13.

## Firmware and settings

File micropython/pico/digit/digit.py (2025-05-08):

from machine import Pin, PWM, RTC
from common.uart_protocol import commandHelper, uartCommand
import time
from common.config import Config

# System constants
LED_PWM_FREQUENCY = 1000  # Hz
LED_DEFAULT_BRIGHTNESS = 0.4  # 40% brightness
MOTOR_PWM_FREQUENCY = 50  # Hz
MOTOR_SPEED_PIN = 11  # Pin for controlling motor speed

# Array sizes
NUM_SEGMENTS = 7  # Number of segments per digit

# Time constants
DEFAULT_WAIT_TIME = 0.01  # seconds
RTC_DEFAULT_YEAR = 2000
RTC_DEFAULT_MONTH = 1
RTC_DEFAULT_DAY = 1
RTC_DEFAULT_WEEKDAY = 0

# File constants
CONFIG_FILE = "digit.json"

# Segment movement sequence constants
EXTEND_SEQUENCE = [2, 3, 4, 5, 0, 1, 6]
RETRACT_SEQUENCE = [5, 0, 1, 2, 3, 4, 6]

# Motor tuples (extend pin, retract pin)
motor1 = (12, 13)
motor2 = (14, 15)
motor3 = (16, 17)
motor4 = (18, 19)
motor5 = (20, 21)
motor6 = (22, 26)
motor7 = (27, 10)
motor_pins = [motor1, motor2, motor3, motor4, motor5, motor6, motor7]
led_pins = [2, 3, 6, 7, 8, 9, 28]

class Motoractuator:
    def __init__(self, speedPin, cwPin, ccwPin):
        self.speed = PWM(Pin(speedPin))
        self.speed.freq(MOTOR_PWM_FREQUENCY)
        self.cw = Pin(cwPin, Pin.OUT)
        self.ccw = Pin(ccwPin, Pin.OUT)
        self.stop()
    
    def extend(self, motor_speed, waitTime):
        try:
            # Convert percentage to PWM duty cycle (0-65535)
            self.speed.duty_u16(int((motor_speed / 100) * 65535))
            self.cw.on()
            time.sleep(waitTime)
        except Exception as e:
            print(f"extend error: {e}")
        finally:
            self.stop()
    
    def retract(self, motor_speed, waitTime):
        try:
            # Convert percentage to PWM duty cycle (0-65535)
            self.speed.duty_u16(int((motor_speed / 100) * 65535))
            self.ccw.on()
            time.sleep(waitTime)
        except Exception as e:
            print(f"retract error: {e}")
        finally:
            self.stop()
    
    def stop(self):
        self.speed.duty_u16(0)
        self.cw.off()
        self.ccw.off()

class Digit:
    # PWM duty cycle max value
    MAX_DUTY_CYCLE = 65535
    
    # Default values for configuration
    DEFAULT_MOTOR_SPEED = 50  # 50% speed
    DEFAULT_WAIT_TIME = 0.02  # 20ms
    DEFAULT_DIGIT = 0
    DEFAULT_TEST_DIGIT = 0
    DEFAULT_SEGMENT_STATE = [0, 0, 0, 0, 0, 0, 0]
    
    def __init__(self, led_pins, percentLED_brightness, motor_pins):
        self.leds = []
        for i in range(NUM_SEGMENTS):
            led = PWM(Pin(led_pins[i]))
            led.freq(LED_PWM_FREQUENCY)
            led.duty_u16(0)
            self.leds.append(led)
        self.conf = Config(CONFIG_FILE)
        self._previousDigitArray = self.DEFAULT_SEGMENT_STATE.copy()
        try:
            self.rtc = RTC()
            current = self.conf.read("previous")
            percentLED_brightness = float(self.conf.read("brightness", default=LED_DEFAULT_BRIGHTNESS))
            self._brightness = int(percentLED_brightness * self.MAX_DUTY_CYCLE)
            self._previousDigitArray = self.conf.read("previous", default=self.DEFAULT_SEGMENT_STATE)
            self._motorspeed = int(self.conf.read("motorspeed", default=self.DEFAULT_MOTOR_SPEED))
            self._waitTime = float(self.conf.read("waitTime", default=self.DEFAULT_WAIT_TIME))
            self._digit = int(self.conf.read("digit", default=self.DEFAULT_DIGIT))
            self._testDigit = int(self.conf.read("alien", default=self.DEFAULT_TEST_DIGIT))
        except Exception as e:
            print(f"Error loading configuration: {e}")
            self._brightness = int(LED_DEFAULT_BRIGHTNESS * self.MAX_DUTY_CYCLE)
            self._motorspeed = self.DEFAULT_MOTOR_SPEED
            self._waitTime = self.DEFAULT_WAIT_TIME
            self._digit = self.DEFAULT_DIGIT
            self._testDigit = self.DEFAULT_TEST_DIGIT
            
        self.actuators = []
        for motor in motor_pins:
            m = Motoractuator(MOTOR_SPEED_PIN, motor[0], motor[1])
            m.stop()
            self.actuators.append(m)

        time.sleep(0.5)  # Short delay before setting initial digit
        self.set_digit(current or self.DEFAULT_SEGMENT_STATE)
    
    def __del__(self):
        for led in self.leds:
            led.duty_u16(0)
        self.conf.__del__()

    @property
    def testdigit(self):
        return self._testDigit
    
    @testdigit.setter
    def testdigit(self, test):
        print(f"test digit={test}")
        self._testDigit = test
        self.conf.write("alien", test)
    
    @property
    def motorspeed(self):
        return self._motorspeed

    @motorspeed.setter
    def motorspeed(self, speed):
        self._motorspeed = speed
        self.conf.write("motorspeed", speed)
    
    @property
    def waitTime(self):
        return self._waitTime
    
    @waitTime.setter
    def waitTime(self, wt):
        self._waitTime = wt
        self.conf.write("waitTime", wt)
    
    @property
    def brightness(self):
        return self._brightness
    
    @brightness.setter
    def brightness(self, b):
        self._brightness = int(b * self.MAX_DUTY_CYCLE)
        self.conf.write("brightness", b)
        for i in range(NUM_SEGMENTS):
            if 1 == self._previousDigitArray[i]:
                self.leds[i].duty_u16(self._brightness)
                print(f"----------\nbrightness {self._brightness} seg={i}")

    def getDigitArray(self, val):
        a = [0] * NUM_SEGMENTS
        for i in range(len(a)):
            a[i] = (val & (0x01 << i)) >> i
        return a
    
    def extend_segment(self, seg):
        if(0 == self._previousDigitArray[seg]):
            self.actuators[seg].extend(self._motorspeed, self._waitTime)
            self.leds[seg].duty_u16(self._brightness)
        self._previousDigitArray[seg] = 1
        self.setPreviousDigitArray(self._previousDigitArray)
        return 1

    def retract_segment(self, seg):
        if(1 == self._previousDigitArray[seg]):
            self.actuators[seg].retract(self._motorspeed, self._waitTime)
            self.leds[seg].duty_u16(0)
        self._previousDigitArray[seg] = 0
        self.setPreviousDigitArray(self._previousDigitArray)
        return 1

    def set_digit(self, digitArray):
        actuatorMoves = 0
        print(f"set_digit: {digitArray}")
        for i in range(NUM_SEGMENTS):
            skipped = True
            if (1 == digitArray[i]) and (0 == self._previousDigitArray[i]):
                self.actuators[i].extend(self._motorspeed, self._waitTime)
                print(f"\t[1] seg {chr(i+97)} extended")  # 'a' is ASCII 97
                self.leds[i].duty_u16(self._brightness)
                actuatorMoves += 1
                skipped = False
            
            if (1 == digitArray[i]) and (1 == self._previousDigitArray[i]):
                self.leds[i].duty_u16(self._brightness)
                print(f"\t[1] seg {chr(i+97)} skipped")
                skipped = False

            if (0 == digitArray[i]) and (1 == self._previousDigitArray[i]):
                print(f"\t[0] seg {chr(i+97)} retracted")
                self.leds[i].duty_u16(0)
                self.actuators[i].retract(self._motorspeed, self._waitTime)
                actuatorMoves += 1
                skipped = False
            
            if skipped:
                print(f"\t[{self._previousDigitArray[i]}] seg {chr(i+97)} skipped")

        self.setPreviousDigitArray(digitArray)
        return actuatorMoves

    def setPreviousDigitArray(self, digitArray):
        self.conf.write('previous', digitArray)
        for i in range(NUM_SEGMENTS):
            self._previousDigitArray[i] = digitArray[i]

    def dance(self):
        actuatorMoves = 0
        for seg in EXTEND_SEQUENCE:
            self.extend_segment(seg)
            time.sleep(DEFAULT_WAIT_TIME)
            actuatorMoves += 1
        for seg in RETRACT_SEQUENCE:
            self.retract_segment(seg)
            time.sleep(DEFAULT_WAIT_TIME)
            actuatorMoves += 1
        return actuatorMoves

    def syncTime(self, h, m, s):
        # time tuple = [year, month, day, weekday, hours, minutes, seconds, subseconds]
        self.rtc.datetime((RTC_DEFAULT_YEAR, RTC_DEFAULT_MONTH, RTC_DEFAULT_DAY, 
                          RTC_DEFAULT_WEEKDAY, h, m, s, 0))
    
    # This method is used to format 12 or 24 hour time
    # parameter 'twelveHour' is a boolean value
    # time tuple = [year, month, day, weekday, hours, minutes, seconds, subseconds]
    def setTimeDisplay(self, twelveHour):
        FIRST_DIGIT_POS = 0
        SECOND_DIGIT_POS = 1
        TENS_OFFSET = 0
        ONES_OFFSET = 2  # Offset for minutes position
        TWELVE_HOUR_BLANK = 'F'  # Character to show for blank first digit in 12-hour format
        
        ready = False
        while not ready:
            t = self.rtc.datetime()
            if t[6] % 10 == self._digit:  # Check if seconds match the current digit position
                ready = True
            time.sleep(0.1)
        
        d = '0'
        if self._digit >= TENS_OFFSET and self._digit < SECOND_DIGIT_POS:
            a = '{0:02}'.format(t[4])  # Format hours as 2 digits
            d = a[self._digit]
            print(f"hours d={d}")
        else:
            a = '{0:02}'.format(t[5])  # Format minutes as 2 digits
            d = a[self._digit - ONES_OFFSET]
            print(f"minutes d={d}")

        # In 12-hour format, blank the first digit if it's 0 (e.g. "01" becomes " 1")
        if twelveHour and d == '0' and self._digit == FIRST_DIGIT_POS:
            d = TWELVE_HOUR_BLANK
        
        v = uartCommand.digitValue
        self.set_digit(self.getDigitArray(v[int(d, 16) if d.isalpha() else int(d)]))

def instructions():
    actions = ['c','d','e','h','l','r','s','t','w']

    while True:
        print("Enter a command:")
        print("\t(c)ycle through digits")
        print("\t(d)igit (d0-d9,dA-dF)")
        print("\t(e)xtend segment (e0-e6)")
        print("\t(h)uman or alien digit (h0-h1)")
        print("\t(l)uminosity(0-9)")
        print("\t(r)etract segment (r0-r6)")
        print("\t(s)peed(10-100)% of segment movement")
        print("\t(t)est digits")
        print("\t(w)ait(15-30 milliseconds) of segment movement")
        print("\t(q)uit")
        cmd = input("command: ")
        validaction = False
        for i in actions:
            if i == cmd[0].lower():
                validaction = True
                print(f"Choice={i} value={cmd[1:]}")
                break
        if validaction:
            a = cmd[0]
            if a.lower() == 'c' or a.lower() == 't':
                v = '0'
                return a.lower(), v
            else:
                v = cmd[1:]
                return a.lower(), v
        else:
            return '',0
        
def main():
    d = Digit(led_pins, LED_DEFAULT_BRIGHTNESS, motor_pins)
    helper = commandHelper()
    finished = False
    
    while not finished:
        seg, value = instructions()

        if seg == 'c':
            print("cycle through digits:")
            for i in range(0,16):
                a = helper.decodeHex(value=i)
                print(f"digit=(0x{a:02x})")
                if 1 == d.testdigit:
                    digitArray = d.getDigitArray(uartCommand.digitTest[int(a)])
                else:
                    digitArray = d.getDigitArray(uartCommand.digitValue[int(a)])
                d.set_digit(digitArray)
                time.sleep(1)
        elif seg == 'd':
            print(f"digit=({value})")
            a = helper.decodeHex(value)
            if 1 == d.testdigit:
                digitArray = d.getDigitArray(uartCommand.digitTest[a])
            else:
                digitArray = d.getDigitArray(uartCommand.digitValue[a])
            actuatorMoves = d.set_digit(digitArray)
        elif seg == 'e':
            i = int(value)
            print(f"extend segment=({i})")
            actuatorMoves = d.extend_segment(i)
        elif seg == 'h':
            d.testdigit = int(value)
            if d.testdigit == 1:
                print("digit type = 'alien'")
            else:
                print("digit type = 'human'")
        elif seg == 'l':
            print(f"luminosity=({value})")
            d.brightness = float(value)/10
        elif seg == 'r':
            i = int(value)
            print(f"retract segment=({i})")
            actuatorMoves = d.retract_segment(i)
        elif seg == 's':
            i = int(value)
            print(f"set_motor_speed({i})")
            d.motorspeed = i
        elif seg == 't':
            actuatorMoves = d.dance()
            print(f"test actuator moves={actuatorMoves}")
        elif seg == 'w':
            i = int(value)
            print(f"set_wait_time({i})")
            d.waitTime = i/100
        else:
            finished = True
    d.__del__()
    del d

if __name__ == "__main__":
    main()

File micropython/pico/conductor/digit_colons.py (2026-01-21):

from machine import Pin, PWM, RTC
from common.uart_protocol import commandHelper, uartCommand
import time
from common.config import Config

# LED constants
LED_PWM_FREQUENCY = 1000  # Hz
LED_DEFAULT_BRIGHTNESS = 0.5  # 100%
MAX_DUTY_CYCLE = 65535
BRIGHTNESS_LIMIT_FACTOR = 0.4
MAX_BRIGHTNESS = MAX_DUTY_CYCLE * BRIGHTNESS_LIMIT_FACTOR

# Motor constants
MOTOR_PWM_FREQUENCY = 50  # Hz
MOTOR_SPEED_PIN = 11

# Hardware configuration
# Motor tuples (extend pin, retract pin)
MOTOR1_PINS = (12, 13)
MOTOR2_PINS = (14, 15)
motor_pins = [MOTOR1_PINS, MOTOR2_PINS]

# LED pins
LED1_PIN = 2
LED2_PIN = 3
led_pins = [LED1_PIN, LED2_PIN]

# Segment constants
NUM_SEGMENTS = 2
DEFAULT_SEGMENT_STATE = [0, 0]

# Time constants
DEFAULT_DELAY = 0.5  # seconds
DANCE_DELAY = 0.01   # seconds
POLLING_DELAY = 0.1  # seconds

# RTC constants
DEFAULT_YEAR = 1970
DEFAULT_MONTH = 1
DEFAULT_DAY = 1
DEFAULT_WEEKDAY = 0
DEFAULT_SUBSECONDS = 0

# Configuration file
CONFIG_FILE = "digit.json"

# Display constants
FIRST_DIGIT_POS = 0
SECOND_DIGIT_POS = 1
TENS_OFFSET = 0
ONES_OFFSET = 2  # Offset for minutes position
TWELVE_HOUR_BLANK = 'F'  # Character to display for blank first digit in 12-hour format

class Motoractuator:
    def __init__(self, speedPin, cwPin, acwPin):
        self.speed = PWM(Pin(speedPin))
        self.speed.freq(MOTOR_PWM_FREQUENCY)
        self.cw = Pin(cwPin, Pin.OUT)
        self.ccw = Pin(acwPin, Pin.OUT)
        self.stop()
    
    def extend(self, motor_speed, wait):
        # try/except block needed as an exception may be thrown without stopping the motor
        try:
            self.speed.duty_u16(int((motor_speed/100)*MAX_DUTY_CYCLE))
            self.cw.on()
            time.sleep(wait)
        except Exception as e:
            print(f"extend error: {e}")
        finally:
            self.stop()
    
    def retract(self, motor_speed, wait):
        # try/except block needed as an exception may be thrown without stopping the motor
        try:
            self.speed.duty_u16(int((motor_speed/100)*MAX_DUTY_CYCLE))
            self.ccw.on()
            time.sleep(wait)
        except Exception as e:
            print(f"retract error: {e}")
        finally:
            self.stop()
    
    def stop(self):
        self.speed.duty_u16(0)
        self.cw.off()
        self.ccw.off()

class DigitColons:
    # Default values for configuration
    DEFAULT_MOTOR_SPEED = 50  # 50% speed
    DEFAULT_WAIT_TIME = 0.02  # 20ms
    DEFAULT_DIGIT = 0
    DEFAULT_TEST_DIGIT = 0
    
    def __init__(self, led_pins, percentLED_brightness, motor_pins):
        self.leds = []
        for i in range(NUM_SEGMENTS):
            led = PWM(Pin(led_pins[i]))
            led.freq(LED_PWM_FREQUENCY)
            led.duty_u16(0)
            self.leds.append(led)
        self.conf = Config(CONFIG_FILE)
        self._previousDigitArray = DEFAULT_SEGMENT_STATE.copy()
        try:
            self.rtc = RTC()
            current = self.conf.read("previous", default=DEFAULT_SEGMENT_STATE)
            percentLED_brightness = float(self.conf.read("brightness", default=LED_DEFAULT_BRIGHTNESS))
            self._brightness = int(percentLED_brightness*MAX_BRIGHTNESS)
            self._previousDigitArray = self.conf.read("previous", default=DEFAULT_SEGMENT_STATE)
            self._motorspeed = int(self.conf.read("speed", default=self.DEFAULT_MOTOR_SPEED))
            self._waitTime = float(self.conf.read("wait", default=self.DEFAULT_WAIT_TIME))
            self._digit = int(self.conf.read("digit", default=self.DEFAULT_DIGIT))
            self._testDigit = int(self.conf.read("alien", default=self.DEFAULT_TEST_DIGIT))
        except Exception as e:
            print(f"Error loading configuration: {e}")
            self._brightness = int(LED_DEFAULT_BRIGHTNESS * MAX_BRIGHTNESS)
            self._motorspeed = self.DEFAULT_MOTOR_SPEED
            self._waitTime = self.DEFAULT_WAIT_TIME
            self._digit = self.DEFAULT_DIGIT
            self._testDigit = self.DEFAULT_TEST_DIGIT
            
        self.actuators = []
        for motor in motor_pins:
            m = Motoractuator(MOTOR_SPEED_PIN, motor[0], motor[1])
            m.stop()
            self.actuators.append(m)

        time.sleep(DEFAULT_DELAY)
        self.set_digit(current or DEFAULT_SEGMENT_STATE)
    
    def __del__(self):
        for led in self.leds:
            led.duty_u16(0)
        self.conf.__del__()

    @property
    def testdigit(self):
        return self._testDigit
    
    @testdigit.setter
    def testdigit(self, test):
        self._testDigit = test
        self.conf.write("alien", test)
    
    @property
    def speed(self):
        return self._motorspeed

    @speed.setter
    def speed(self, speed):
        self._motorspeed = speed
        self.conf.write("speed", int(speed))
    
    @property
    def wait(self):
        return self._waitTime
    
    @wait.setter
    def wait(self, wt):
        self._waitTime = wt
        self.conf.write("wait", wt)
    
    @property
    def brightness(self):
        return self._brightness
    
    @brightness.setter
    def brightness(self, b):
        self._brightness = int(b*MAX_BRIGHTNESS)
        self.conf.write("brightness", b)
        for i in range(NUM_SEGMENTS):
            if 1 == self._previousDigitArray[i]:
                self.leds[i].duty_u16(self._brightness)

    def getDigitArray(self, val):
        a = [0] * NUM_SEGMENTS
        for i in range(NUM_SEGMENTS):
            a[i] = (val & (0x01 << i)) >> i
        return a
    
    def extendSegment(self, seg):
        if(0 == self._previousDigitArray[seg]):
            self.actuators[seg].extend(self._motorspeed, self._waitTime)
            self.leds[seg].duty_u16(self._brightness)
        self._previousDigitArray[seg] = 1
        self.setPreviousDigitArray(self._previousDigitArray)
        return 1

    def retractSegment(self, seg):
        if(1 == self._previousDigitArray[seg]):
            self.actuators[seg].retract(self._motorspeed, self._waitTime)
            self.leds[seg].duty_u16(0)
        self._previousDigitArray[seg] = 0
        self.setPreviousDigitArray(self._previousDigitArray)
        return 1

    def set_digit(self, digitArray):       
        actuatorMoves = 0
        for i in range(NUM_SEGMENTS):
            if (1 == digitArray[i]) and (0 == self._previousDigitArray[i]):
                self.actuators[i].extend(self._motorspeed, self._waitTime)
                self.leds[i].duty_u16(self._brightness)
                actuatorMoves += 1
            
            if (1 == digitArray[i]) and (1 == self._previousDigitArray[i]):
                self.leds[i].duty_u16(self._brightness)

            if (0 == digitArray[i]) and (1 == self._previousDigitArray[i]):
                self.leds[i].duty_u16(0)
                self.actuators[i].retract(self._motorspeed, self._waitTime)
                actuatorMoves += 1

        self.setPreviousDigitArray(digitArray)
        return actuatorMoves
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

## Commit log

2024-03-07 initial draft
    [fullsize-v2-magnet holder 0.stl, fullsize-v2-magnet holder 135.stl, fullsize-v2-magnet holder 180.stl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]
2024-03-21 initial checkin for end to end test
    [7-segment-back-plate-b.stl, 7-segment-backplate-a-cross-beam-a.stl, 7-segment-backplate-a-cross-beam-b.stl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]
2024-03-23 tested with daisy-chained shift registers
    [7-segment-back-plate-b.stl, 7-segment-backplate-a-cross-beam-a.stl, 7-segment-backplate-a-cross-beam-b.stl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]
2024-03-26 updated wiring without shift register
    [7-segment-rail-gear-seg-a.stl, 7-segment-rail-gear-seg-g.stl, 7-segment-seg-a.stl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]
2024-04-04 interim checkin
    [7-segment-motor-mount-seg-a.stl, 7-segment-rail-gear-seg-a.stl, 7-segment-rail-gear-seg-g.stl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]
2024-04-30 split to private repo
    [7-segment-back-plate.stl, 7-segment-digit1-back-plate.stl, 7-segment-face-double.stl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]
2024-07-18 updated drawings
    [7-segment-back-plate.stl, 7-segment-bumper-digit3-seg-a.stl, 7-segment-colon-lower-seg.stl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]
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2024-07-18 removed outdated stl files
    [7-segment-bumper-digit3-seg-a.stl, 7-segment-colon-lower-seg.stl, 7-segment-colon-upper-pin.stl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]
2024-09-25 updated stl files
    [7-segment-digit3-motor-mount-seg-a.3mf, 7-segment.blend, colon-lower-seg.stl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]
2024-09-30 updated bumper
    [digit-bumper.stl]
2024-10-03 updated design
    [7-segment.blend, display-bambu-lab.3mf, illustration-face.blend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]
2024-10-03 updated name of cad design
    [7-segment.blend, kineticdisplay.blend]
2024-10-16 updated documentation and blender file
    [7-segment-digit3-motor-mount-seg-a.3mf, digit-motor-mount.3mf, digit-motor-mount.stl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]
2024-10-27 added python code
    [filesandsettings.xlsx, kineticdisplay.blend, measurements.xlsx]
2024-10-31 added images and documentation
    [digit-bumper.stl, digit-rack-gear.stl, digit-rail-gear.stl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]
2024-11-01 updated scheduler
    [display-bambu-lab.3mf, kineticdisplay.blend]
2024-11-02 fixed bug in json around the 56 minute mark
    [display-bambu-lab.3mf, filesandsettings.xlsx]
2024-11-03 fixed time sync bug after hybernation
    [display-bambu-lab.3mf]
2024-11-06 updated schedule json files
    [digit-pcb-gasket.stl, digit-rack-gear.stl, digit-shockplate.stl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]
2024-11-21 updated digit manual program
    [colon-pin.stl, display-bambu-lab.3mf, kineticdisplay.blend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]
2024-12-03 minor fixes to actuator
    [kineticdisplay.blend]
2024-12-12 fixed minor bugs and added new features
    [digit1-gasket.stl, display-bambu-lab.3mf, kineticdisplay.blend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]
2024-12-12 added uf2 files as UART doesn't work with micropython build 1.24 or greater
    [config.py, dhttest.py, digit.py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]
2024-12-17 refactored tests
    [digit1-gasket.stl, display-bambu-lab.3mf, kineticdisplay.blend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]
2024-12-17 Cleaning up unused files in repo
    [7-segment-test.blend, motor-v3.blend]
2024-12-17 updated the powerbank to be the stand
    [kineticdisplay.blend]
2024-12-22 initial draft of documentation
    [kineticdisplay.blend]
2024-12-28 doc drafts, updated motor mount
    [digit-motor-mount.3mf, digit-motor-mount.stl, display-bambu-lab.3mf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]
2025-01-15 updated bambu lab project
    [display-bambu-lab.3mf]
2025-01-19 changed stand
    [display-bambu-lab.3mf, face-digit0-1.stl, face-digits2-3.stl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]
2025-01-25 moved blender file to private repo
    [feltcutout.blend, gearcalculations.xlsx, kineticdisplay-digit3-seg-a-bumper.stl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]
2025-01-25 migrated test files from public to private
    [digit1-back-plate.stl, digit1-gasket.stl, digit2-gasket.stl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]
2025-01-27 added dupont connector steps for actuators
    [display-bambu-lab.3mf]
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2025-02-02 minor fix to digit pcb images
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2025-02-21 changed display face
    [digit-gear30.stl, digit0-1-face.stl, digit2-3-face.stl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]
2025-02-28 broke out the single bambu lab project into muliple by type, color, and plate
    [digit-back-plate.3mf, display-bambu-lab.3mf, nylon-smooth-black.3mf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]
2025-03-04 updated documentation
    [nylon-smooth-black.3mf, pla-smooth-white.3mf, pla-textured-white.3mf]
2025-03-12 updated fdm files
    [pla-smooth-black.3mf]
2025-03-13 updated diagrams
    [nylon-smooth-black.3mf]
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2025-03-22 updated bambu studio file
    [pla-textured-white.3mf]
2025-03-26 updated diagrams to pcb assembly
    [digit2-back-plate.stl, pla-smooth-black.3mf, pla-textured-white.3mf]
2025-03-28 updated bambu project files
    [digit-gasket.3mf, digit1-gasket.stl, pla-smooth-white.3mf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]
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2025-04-01 Fixed bugs in controller pcb md doc, added components
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2025-04-02 Fixed labelling error in controller PCB
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2025-04-10 corrected UART wiring diagram
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2025-04-15 cleaned up fdm file references and provided details and totals
    [colon-lower-seg.stl, digit-back-plate.3mf, digit-gasket.3mf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]
2025-04-15 fixed table formatting
    [filesandsettings.xlsx]
2025-04-15 Updated formatting of 3d print doc
    [filesandsettings.xlsx]
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2025-04-19 added more docs and images
    [pla-smooth-black.3mf]
2025-04-19 fixed bugs with external humidity
    [digit_colons.py, externalTemp.py, uart_command.py]
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2025-04-22 updated stl list
    [colon-pin.stl]
2025-04-22 Updated table of filament types for 3d prints
    [digitcolon-gasket.stl]
2025-04-23 removed files that were no longer needed
    [filesandsettings.xlsx]
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2025-04-24 fixed typo with resistor spec
2025-04-24 Added a small powerbank and stand.
    [kineticdisplay-powerbank.stl, pla-smooth-white.3mf]
2025-04-28 Updated digit 2 back plate design
    [digit2-back-plate.stl, pla-smooth-black.3mf, powerbank-small.stl]
2025-04-29 Updated time sync code to be more robust by calling a different api if the first one fails
    [externalTemp.py, syncRTC.py, testAPIs.py]
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2025-04-30 Updated display face design
    [digit0-1-face.stl, digit2-3-face.stl, pla-textured-white.3mf]
2025-05-01 Updated tabs and seams to digit face
    [digit0-1-face.stl, digit2-3-face.stl, pla-textured-white.3mf]
2025-05-01 updated ai corrections so the code would actually work
    [digit.py, digit_colons.py, uart_digit.py]
2025-05-01 fixed bug in ai naming
    [digit.py]
2025-05-01 Added more error handling
    [uart_digit.py]
2025-05-01 updated digit face
    [pla-textured-white.3mf]
2025-05-02 refactored code to make naming more consistent and improve error handling
    [digit.py, digit_colons.py, uart_command.py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]
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2025-05-06 Added documentation, enhanced error handline, added backup geolocation
    [externalTemp.py]
2025-05-06 Added documentation, calibration function, improved error handling
    [photoresistor.py]
2025-05-06 removed additions from AI which caused memory issues
    [config.py, digit_colons.py, photoresistor.py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]
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2025-05-07 Added worldtimeapi as timezone backup to retrieve time
    [pla-smooth-white.3mf]
2025-05-07 fixed issue with test on startup setting showing value in config file
    [picowifiserver.py]
2025-05-07 fixed test on startup logic
    [uart_command.py]
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2025-05-08 fixed bugs with lazy loading
    [uart_command.py]
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2025-05-08 fixed formatting problem in settings web page
    [picowifiserver.py, uart_command.py]
2025-05-09 fixed bugs caused by name changes
    [syncRTC.py, testAPIs.py]
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2025-05-16 small updates to spaces in design
    [digit0-1-face.stl, digit2-3-face.stl, digit2-back-plate.stl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]
2025-05-31 updated schedule 0 sleep event to not collide with the time event
    [pla-smooth-white.3mf, pla-textured-white.3mf]
2025-06-01 updated precision of hybernation
    [nylon-smooth-black.3mf, pla-smooth-black.3mf]
2025-06-01 Minor fixes to parts FDM fabrication
    [digit1-gasket.stl, tpu-smooth-black.3mf]
2025-12-12 changed the script to overwrite and not error when encountering existing files
    [nylon-smooth-black.3mf, pla-smooth-white.3mf]
2026-01-10 changed the way time and dst work
    [pla-smooth-white.3mf, pla-textured-white.3mf, seg-a.3mf]
2026-01-11 Updated fixes to get the external temp reading to work
    [externalTemp.py, picowifiserver.py]
2026-01-31 fixed bug with obtaining the lat/lon from the config file
    [externalTemp.py]
2026-03-08 fixed bug to set the DST when it occurs
    [syncRTC.py, test_syncRTC_hardware.py]
